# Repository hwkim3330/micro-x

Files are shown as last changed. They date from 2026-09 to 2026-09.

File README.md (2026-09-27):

# MICRO X — Rev C

*An independently designed 14-servo small biped robot (Microduck-compatible 61-obs → 14-action, 50 Hz policy interface) with original CAD, printability/interference/balance checks and a MuJoCo model, all numbers generated from measured artifacts. Rev C is digitally verified only; no physical build or walking test yet. [Browser 3D viewer](https://hwkim3330.github.io/micro-x/web/).*

**소유자 hwkim3330이 제작·판매를 목표로 개발하는 상업용 독자 설계 소형 두발 로봇.** 공룡을 고집하지 않습니다. 넓은 부리와 큰 눈, 크림 몸에 호박색 부리·발, 두꺼운 벽. Microduck의 14축 정책 인터페이스(61 관측 → 14 행동, 50 Hz)를 그대로 쓰되, 기구·외장·서보 배치·전장 자리는 독자 설계입니다. 원본 기구를 그대로 쓰는 비상업 비교 시험기 [Micro Rex](https://github.com/hwkim3330/micro-rex)는 별도 저장소로 보존합니다.

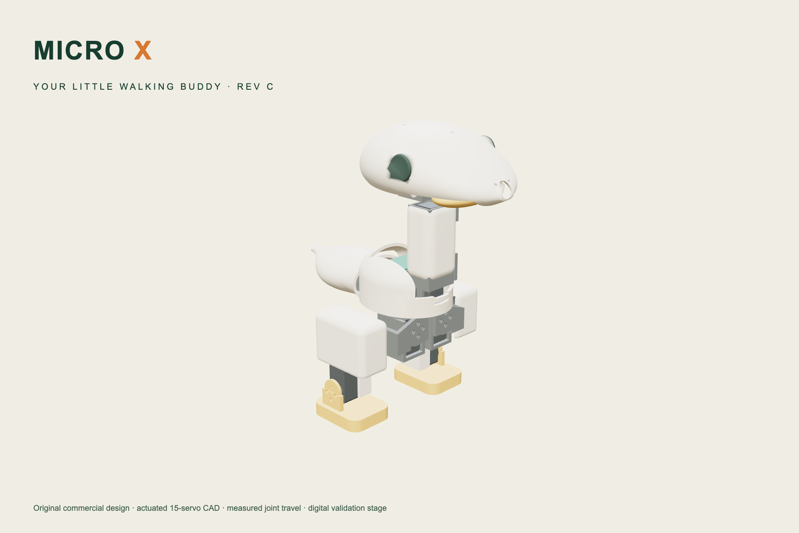
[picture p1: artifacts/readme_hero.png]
Micro X Rev C — 실제 CAD 렌더


[제품 페이지 · 3D 뷰어](https://hwkim3330.github.io/micro-x/web/) · [학습 Lab](https://hwkim3330.github.io/micro-x/web/lab.html) · [보행 실험](https://hwkim3330.github.io/micro-x/web/simulator.html) · [설계](docs/DESIGN.md) · [조립](docs/ASSEMBLY.md) · [목표와 진행 기준](PROJECT_GOAL.md)

**현재 단계: Rev C 구동 설계 · 디지털 검증 완료, 실물 검증 전.** 출력·조립·보행·내구 시험은 아직 없습니다. 판매 가능한 완제품이 아닙니다.

## Rev C까지 바뀐 것

| | Rev A | Rev B → C |
|---|---|---|
| 설계 자세 | HOME(다리 굽은 자세) 측정 → 축이 5° 기울고 브래킷이 사선 | **qpos 0(곧게 선 자세) 측정 → 모든 축이 정렬, 브래킷이 평평하게 출력** |
| 서보 고정 | 관절마다 판 두 장으로 감싸는 클레비스 | **기준 로봇과 같은 방식: 한쪽 링크의 U자 채널 + 혼 판 한 장** |
| 출력물 질량 | 422 g | Rev B 347 g → **Rev C 440 g** (벽 2.4 → 3.0 mm, 20개 부품; 튼튼함을 위해 되돌린 부분) |
| 가동 범위 | 추측한 값을 모델에 기입 | **`tools/travel.py`가 0.05 rad씩 돌려 측정**, 그 값이 곧 MuJoCo 관절 한계 |
| 머리 | 타원체 한 덩이 | 단면 8개 로프트의 둥근 머리, **넓은 호박색 부리**, 렌즈 후드 코, **쉘과 한 몸인 Ø22 버튼 눈**(부품 아님) |
| 출력성 | 미측정 | **`artifacts/printability.json`**: 20개 전부 220×220 침대, 최대 오버행 27 % |

## 숫자

아래 표는 전부 `artifacts/`의 JSON에서 `tools/report.py`가 채웁니다. 손으로 적은 성능 숫자는 없습니다.

<!-- measured:summary -->
| 항목 | 값 | 출처 |
|---|---|---|
| 출력 부품 | 20개, 436.2 g (PLA 꽉 찬 기준, 실제 인필은 더 가벼움) | `artifacts/parts.json` |
| 구매품 | 18개, 399.0 g (카탈로그) | 같은 파일 |
| 모델 총질량 · 무게중심 | 834.3 g, 무게중심 z 141.68 mm, 지지영역 여유 12.71 mm | `artifacts/balance.json` |
| 간섭 | 설계 자세 정적 겹침 0건 / 측정 가동 범위 안 스윕 충돌 0 | `artifacts/interference.json` |
| 출력성 | 20개 모두 220×220 침대, 최악 오버행 30 %, 침대 접촉 0 mm² 4개(skull, right_upper_leg, left_upper_leg, neck_sleeve)는 브림/서포트 필요 | `artifacts/printability.json` |
| 공식 가중치 (무수정) | 15회 중 15회 직립, 추종 게이트 6/15 통과 | `artifacts/compat_evaluation.json` |
<!-- /measured -->

## 측정된 가동 범위

`tools/travel.py`가 관절마다 0.05 rad씩 돌려 정확한 STEP 불리언으로 충돌을 찾은 값이고, 그대로 MuJoCo 관절 한계가 됩니다.

<!-- measured:travel -->
| 관절 | 왼쪽 | 오른쪽 |
|---|---|---|
| 고관절 요 | -28.6° … +29.8° | -29.8° … +28.6° |
| 고관절 롤 | -22.9° … +20.1° | -20.1° … +22.9° |
| 고관절 피치 | -90.0° … +51.6° | -51.6° … +90.0° |
| 무릎 | -90.0° … +63.0° | -63.0° … +90.0° |
| 발목 | -31.5° … +31.5° | -31.5° … +31.5° |
| 목 피치 | -11.5° … +37.2° | (단일) |
| 머리 피치 | -34.4° … +34.4° | (단일) |
| 머리 요 | -114.6° … +43.0° | (단일) |
| 머리 롤 | -5.7° … +8.6° | (단일) |
| 턱 | +0.0° … +5.7° | (단일) |

탐색 상한: 고관절 요 ±30°, 고관절 롤 ±23°, 고관절 피치 ±90°, 무릎 ±90°, 발목 ±90°, 목 피치 ±60°, 머리 피치 ±90°, 머리 요 ±115°, 머리 롤 ±25°, 턱 ±40°. 상한에 도달한 값은 기구가 아니라 탐색 범위가 끝난 것입니다.
<!-- /measured -->

## 정적 기울기 한계

<!-- measured:tip -->
| | Micro X | **Microduck (원본)** | **Micro Cat** |
|---|---|---|---|
| **뒤로 기울기** | 5.5° | 8.5° | 17.7° |
| 앞으로 기울기 | 18.0° | 13.25° | 19.25° |
| 옆으로 기울기 | 24.9° | 23.8° | 25.25° |
| 무게중심 높이 (mm) | 138.0 | 141.1 | 135.7 |
| 질량 (g) | 834.3 | 737.2 | 872.5 |

`tools/tip_study.py`: 기울기마다 몸을 회전시켜 바닥에 내려놓고 접촉점을 다시 계산합니다. 원본은 HOME에서 **발바닥이 평평하지 않아** 뒤꿈치 선으로 서 있고, 무게중심이 그 선보다 21 mm 앞에 있어 발끝이 닿을 때까지 앞으로 넘어갑니다. 표의 값은 그렇게 안정된 자세부터 넘어질 때까지의 각도입니다. 강체·정적이며 접촉 강성·마찰·동역학은 없습니다.
<!-- /measured -->

## 속도·회전 숫자는 믿지 마세요

<!-- measured:harness -->
| 모델 | 전진 명령 추종 (최대) | 회전 명령 추종 (최대) |
|---|---|---|
| microduck_reference | 45 % | 9 % |
| micro_x | 33 % | 1 % |

기준 로봇 자신이 자기 명령을 못 따르므로, **이 하네스의 절대 속도·회전 숫자는 설계 근거로 쓸 수 없습니다.** 같은 하네스 안에서의 모델 간 상대 비교만 의미가 있습니다.
<!-- /measured -->

## 설계 개요

- **관절**: 좌우 고관절 요·롤·피치, 무릎, 발목(10) + 목 피치, 머리 피치·요·롤(4) + 턱(1).
- **피벗·축**: `engineering/functional_layout.json` (기준 로봇을 qpos 0에서 측정한 기능 치수). 서보 몸체 방향만 두 곳에서 바꿨고 이유를 같은 파일에 적었습니다.
- **서보**: XL330급. 인터페이스 치수와 발주 전 확인 항목은 `engineering/actuator_interface.json`. 케이스 홀 패턴은 아직 모델에 없습니다.
- **패키징**: 2S 18650급 배터리는 꼬리 커버 안, 보드(최대 50 × 27 mm)는 고관절 서보 위 데크, 카메라는 주둥이 끝.
- **외장 7개**(몸통·목 커버·머리·아래 부리·꼬리·발 2)만 보이고 나머지는 프레임. 눈은 쉘과 한 몸인 버튼, 손·발톱 없음.
- **배색**: 따뜻한 크림 쉘 + 호박색 부리·발 + 그래파이트 관절. 몸통 아래는 도색으로 한 톤 낮춥니다.
- **튼튼함**: 쉘 벽 3.0 mm, 서보 채널 벽 3.0 mm, 고관절 리브 4 mm + 상하 거싯, 발바닥 4 mm 스킨. 낙하 시험은 아직 없습니다.

## 재생성

```sh
uv venv --python 3.11 .venv && uv pip install --python .venv/bin/python -r requirements.txt
.venv/bin/python cad/build.py            # 20 STEP/STL + GLB 리그 + parts.json
.venv/bin/python cad/compat_model.py     # models/micro_x_14.xml, models/rig.json
.venv/bin/python tools/travel.py         # 관절별 가동 범위 측정 → engineering/joint_travel.json
.venv/bin/python cad/compat_model.py     # 측정값을 관절 한계로 반영
.venv/bin/python tools/interference.py   # 정적 + 가동 범위 안 간섭
.venv/bin/python tools/balance.py && .venv/bin/python tools/printability.py && .venv/bin/python tools/documents.py
.venv/bin/python tools/validate.py && .venv/bin/python -m unittest discover -s tests

uv venv --python 3.12 .venv-policy && uv pip install --python .venv-policy/bin/python -r requirements-policy.txt
.venv-policy/bin/python tools/fetch_compat.py
.venv-policy/bin/python tools/evaluate_compat.py --seconds 10 --seeds 3
.venv-policy/bin/python runtime/training_service.py   # Lab http://127.0.0.1:5201/web/lab.html

npm ci && node --test tests/learning.test.mjs
CHROME_PATH=/path/to/chrome node tools/test-web.mjs && node tools/test-lab.mjs && node tools/test-simulator.mjs && node tools/test-compat-web.mjs
```

## 권리와 판매 방향

원본 기구·CAD 생성 소스·모델·도면은 소유자 권리를 유보합니다(소유자의 상업 이용을 제한하는 비상업 라이선스가 아닙니다). 웹·도구 코드는 MIT, Three.js는 MIT. 공식 추론 코드·가중치(Apache-2.0)는 저장소에 재배포하지 않고 로컬 캐시에만 내려받습니다. 상세: [LICENSE](LICENSE) · [THIRD_PARTY.md](THIRD_PARTY.md) · [PROVENANCE.md](docs/PROVENANCE.md). 제품명·디자인 권리 검토와 공급자 견적은 출시 전 별도 게이트입니다.

### 실제 실행 보드

소형 Radxa Zero 3W 4GB를 첫 실물 검증 후보로 정했습니다. 보행·행동 계산은 로봇 내부, 학습은 PC에서 실행하는 구조입니다. [배선 구상·전체 신경망 CPU 실측·미검증 항목](docs/ONBOARD_COMPUTE.md)을 확인하세요. 실제 보드·전원 검증 전이며 기존 7.4 V BAM 실험은 XL330의 실물 전원 사양이 아닙니다.

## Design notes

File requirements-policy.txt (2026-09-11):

mujoco==3.10.0
numpy>=2,<3
onnxruntime==1.24.1
onnx>=1.17,<2
torch==2.10.0
better-actuator-models @ git+https://github.com/Rhoban/bam.git@62bd8ce12154340be97e06f7f41a0ca8f116d967

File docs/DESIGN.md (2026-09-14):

# Micro X Rev C — 설계

Rev C는 Rev B 위에서 **공룡 형상을 버리고, 넓은 부리와 큰 눈을 가진 둥근 머리로 바꾸고, 벽을 두껍게** 한 판입니다. 기구·측정·검증 방식은 Rev B 그대로입니다. 아래 Rev B 설명이 그대로 적용되며, Rev C 차이는 이 절 끝에 있습니다.

Rev B는 Rev A를 버리고 **기준 로봇의 관절 배치를 측정해 그 위에 처음부터 다시 그린 설계**입니다. 바뀐 것은 세 가지입니다.

1. **설계 자세를 바꿨습니다.** 예전에는 HOME 자세(다리가 굽은 자세)에서 치수를 쟀기 때문에 모든 피벗 축이 5° 기울어 있었고, 브래킷마다 기울어진 형상이 필요했습니다. Rev B는 `qpos = 0`(다리가 곧게 선 자세)에서 측정합니다. 그래서 **모든 관절 축이 X·Y·Z에 정렬**되고, 브래킷이 전부 단순한 직육면체 조합이 되어 서포트 없이 평평하게 출력됩니다. 정책의 HOME 각도는 기구에 굳히지 않고 그냥 관절 각도로 둡니다.
2. **서보 고정 방식을 기준 로봇과 같게 했습니다.** Rev A는 관절마다 판 두 장으로 서보를 감싸는 클레비스 구조여서 부피가 크고 서보가 밖으로 드러났습니다. Rev B는 **서보 몸체가 한쪽 링크의 U자 채널에 들어가고, 이웃 링크는 혼에 볼트로 붙는 판 한 장**입니다. 부품이 얇아지고 가벼워졌습니다(출력물 422 g → 347 g).
3. **가동 범위를 추측하지 않고 측정합니다.** `tools/travel.py`가 관절마다 0.05 rad씩 돌려 가며 정확한 STEP 불리언으로 충돌을 찾아 **실제로 움직일 수 있는 각도**를 구하고, 그 값이 그대로 MuJoCo 관절 한계가 됩니다.

좌표계는 mm, X 앞, Y 왼쪽, Z 위, 바닥 Z=0, 몸통 기준 프레임 Z=120입니다. 생성기는 `cad/build.py`, 배치는 `cad/layout.py`, 서보 인터페이스는 `cad/servo.py`, 측정값은 `engineering/functional_layout.json`입니다.

## 구성

| 부위 | 내용 |
|---|---|
| 몸통 | 섀시(바닥판·고관절 요 서보 박스 2개·전장 데크·배터리 트레이) + 알 모양 쉘(아래는 직선 통, 위는 돔) |
| 꼬리 | 배터리 커버. 2S 18650급 팩(65 × 37 × 19)이 들어가고 M3 2개로 트레이에 고정 |
| 다리 | 요·롤 브래킷 → 고관절 브래킷 → 허벅지 쉘(고관절 피치 + 무릎 서보) → 종아리(발목 서보) → 발 |
| 목 | 두 서보가 세로로 쌓인 튜브 + 둥근 커버. 커버는 목과 함께 기울어짐 |
| 머리 | 요크(머리 요 서보) → 머리 프레임(머리 롤 + 턱 서보, 카메라 벽, 두개골 보스) → 두개골 로프트 + 아래턱 |

머리는 **단면 8개를 잇는 로프트**입니다. 눈 위가 가장 넓고 앞으로 길게 좁아지며, 넓은 호박색 아래 부리가 입을 덮습니다. 기준 로봇의 머리 외형(122 × 92 × 59 mm)에 맞춰 134 × 108 × 60 mm로 잡았습니다. 눈·손·발톱 같은 **떨어질 부품은 없습니다.** 눈은 쉘에서 8 mm 뿌리로 솟은 Ø22 버튼(테두리가 수직이라 도색 경계가 선명), 카메라는 코 자리 렌즈 후드 안에 있습니다.

## 서보 15개의 자리

| 관절 | 서보 몸체가 있는 링크 | 혼 판을 가진 링크 |
|---|---|---|
| 고관절 요 | 몸통 섀시 | 요·롤 브래킷 |
| 고관절 롤 | 요·롤 브래킷 | 고관절 브래킷 |
| 고관절 피치 | 허벅지 | 고관절 브래킷 |
| 무릎 | 허벅지 | 종아리 |
| 발목 | 종아리 | 발 |
| 목 피치 | 목 튜브 | 몸통 섀시 |
| 머리 피치 | 목 튜브 | 머리 베이스 |
| 머리 요 | 요크 | 머리 베이스 |
| 머리 롤 | 머리 프레임 | 요크 |
| 턱 | 머리 프레임 | 아래턱 |

피벗과 축은 기준 로봇 측정값 그대로입니다. 서보 **몸체 방향**만 두 곳에서 바꿨고(`design_servo_overrides`), 이유를 파일에 적었습니다: 머리 롤 서보는 장축을 세워 좁은 뒤통수에 넣었고, 턱 서보는 넓은 쪽으로 향하게 해 부리 팔이 머리 요 서보를 피하도록 했습니다.

## 측정된 가동 범위

`engineering/joint_travel.json`. 왼쪽/오른쪽이 다른 것은 실제로 다르기 때문입니다(브래킷이 좌우 대칭이라 회전 방향에 따라 닿는 곳이 다름).

| 관절 | 측정 가동 범위 | 서보 정격 기준 |
|---|---|---|
| 고관절 요 | -26° … +30° | ±30° |
| 고관절 롤 | -20° … +17° | ±23° |
| 고관절 피치 | -90° … +63° | ±90° |
| 무릎 | -90° … +63° | ±90° |
| 발목 | ±52° | ±90° |
| 목 피치 | -12° … +40° | ±60° |
| 머리 피치 | ±34° | ±90° |
| 머리 요 | ±115° | ±115° |
| 머리 롤 | ±17° | ±25° |
| 턱 | 0° … +17° | 0…40° |

목 피치와 턱이 가장 좁습니다. 목은 서보가 세로로 쌓여 몸통 지붕과 가깝고, 턱은 부리가 카메라 벽에 닿습니다. 다음 개선 대상입니다.

## 출력 (artifacts/printability.json)

20개 부품 모두 220 × 220 침대에 들어갑니다. 최대 오버행 면적 비율은 27 %이고, 부품마다 출력 방향이 `models/print/`에 고정되어 있습니다. 대부분의 브래킷은 면 하나를 침대에 붙이고 벽이 전부 수직이라 서포트가 필요 없습니다. 몸통 쉘은 열린 쪽을 아래로 놓아 테두리 467 mm²가 침대에 닿습니다. 아래턱과 꼬리는 곡면이라 브림이 필요합니다.

## 검증 상태

- 20개 출력 부품 모두 STEP 왕복·닫힌 메시 통과, 347 g(PLA 꽉 찬 기준). 구매품 18개 399 g. 모델 총 746 g (Microduck 780 g).
- 설계 자세 정적 겹침 **0건**, 측정 가동 범위 안의 관절별 샘플 충돌 **0건** (`artifacts/interference.json`).
- HOME 자세 기립 높이 119.3 mm, 무게중심 141 mm, 발 지지영역 안 여유 12.2 mm (`artifacts/balance.json`).
- 변경 없는 공식 보행·서기 가중치를 CAD 기반 14축 모델에서 실행: 15회 모두 10초 직립, 속도·방향 기준은 정지·서기 6회만 통과 (`artifacts/compat_evaluation.json`).

## 남은 일

- 서보 케이스 홀 확인 후 몸체 고정 나사 추가, 케이블 경로.
- IMU·마이크·스피커·전원 보드 배치(데크는 50 × 27 mm까지).
- 목 피치와 턱 가동 범위 확대.
- 출력 공차 시편 → 다리 한 쪽 → 전체 조립 → 보행 시험.

## Rev C 차이 (2026-09-14)

| 항목 | Rev B | Rev C | 이유 |
|---|---|---|---|
| 형상 | 티렉스 주둥이 | 둥근 머리 + 넓은 부리, 크림/호박 배색 | 사용자 요청: 공룡 아니어도 되고 귀엽게; Microduck 쪽이 낫다는 평가를 기준으로 비율을 그쪽에 맞춤 |
| 몸통 쉘 | 아래 121 mm에서 끝남 | 116 mm까지 내려 고관절 서보를 덮음 | 서보가 밖으로 드러나 보이던 문제 |
| 턱 서보 | 피벗 y 18 mm | y 14.5 mm | 머리를 기준 로봇 크기로 줄이자 서보가 쉘 밖으로 나가서 안쪽으로 이동 |
| 쉘 벽 | 2.4 mm | 3.0 mm | 낙하 강도. 출력물 347 → 440 g (버튼 눈·긴 부리 포함) |
| 서보 채널 벽 | 2.4 mm | 3.0 mm | 서보 주변이 가장 먼저 깨지는 곳 |
| 고관절 브래킷 | 3 mm 판 두 장 + 리브 | 롤 리브 4 mm + 상하 코너 거싯 | 브래킷을 상자로 닫는 건 롤 서보와 겹쳐 불가; 리브 보강으로 대체 |
| 허벅지 쉘 | 2.1 mm | 3.0 mm, 라운드 6 | |
| 발 | 스킨 2.5 mm | 스킨 4 mm, 판→바닥 연결 4 mm | |
| 눈 | 도색 마스크(좌표가 형상을 못 따라가 얼룩) | 쉘에서 솟은 Ø20 버튼(라운드 테두리) + 앞면 도색 | 곡면 위 접시는 앞쪽이 뚫려 초승달이 되어 버튼으로 바꿈; 부품 아님 |
| 발목 가동 | ±52° | ±32° | 두꺼운 종아리 채널이 발을 더 일찍 막음. 보행 정책 HOME 발목 ±26°는 안에 있음 |
| 정적 여유 | 12.0 mm | 10.6 mm | 부리가 앞으로 나가 무게중심이 앞쪽으로 이동 |
| 총질량 | 746 g | 838 g | Microduck 780 g보다 7 % 무거움 |

무게 증가는 튼튼함의 대가입니다. 서보 토크 여유가 줄었으므로 실물에서 보행이 힘들면 인필을 낮추거나 쉘만 2.4 mm로 되돌리는 것이 첫 조정입니다.

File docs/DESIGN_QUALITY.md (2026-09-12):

> Rev A(2026-09-13)에서 P0 외형 설계가 폐기되었습니다. 현재 설계 원칙과 검증 상태는 [DESIGN_REVA.md](DESIGN_REVA.md)를 보세요. 아래는 P0 기록입니다.

# Cute appearance and measurable durability

The user requested a cute, robust product that can compete with Microduck. We treat that as a design and verification objective, not an achieved comparative claim.

## Implemented in the current CAD

- Large eyes now have dark pupils and two highlights in the GLB paint mask. These marks are a paint/multicolor finish specification, not extra detachable CAD components. STL remains geometry-only; no paint adhesion or wear resistance is implied.
- Adhesive-only eye spheres are replaced by caps with an integral Ø10 mm rear boss, Ø2.6 mm by 7 mm pilot and a 2 mm integrated skull support plate with Ø3.4 mm clearance. Intended fastening is an M3 plastic thread-forming screw fitted from inside the skull. Candidate M3×8 length with a 1 mm washer gives approximately 5 mm engagement; verify actual chosen screw head, thread, torque and clearance before ordering. Thread-forming fit is material/process specific and has not been validated.
- Forearms, their torso posts and decorative toe projections are removed. Continuous rounded soles retain the existing ankle interface. This reduces parts and exposed projections; strength and drop performance still require physical tests.
- Q4 shares the same new eye/head geometry, avoiding two independent cosmetic/retention designs.

## What must be measured

`engineering/acceptance.json` records proposed test targets with **null results**. Eye retention, loaded joint endurance, drop behavior, drive-module replacement time and actual walking tests remain open. No physical robustness conclusion follows from watertight STL or lack of static CAD overlap.

Cost reduction must preserve load capacity and service life. Current load screening rejects the cheaper B2 candidate under the stated assumptions; see `docs/PLATFORMS.md`. The next drive design needs verified motor data, supported shafts/bearings, cable strain relief and a locking/retention strategy.

Both eye print STLs place the rear boss on the bed; support is still needed under the cap rim. Q4 shared parts reuse the exact B2 print STL bytes, preserving the same print setup rather than silently rotating a common part differently.

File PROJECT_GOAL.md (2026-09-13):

# Micro X product design goal

Owner: hwkim3330. Commercial, independently designed T-rex companion robot that keeps the Microduck 14-axis policy interface. The noncommercial Micro Rex repository stays separate as the unchanged-Microduck reference rig.

## Direction as of 2026-09-13 (Rev B)

User direction, in order: the P0 appearance was rejected; make X as cute as the original Microduck; drop parts that can break off (eyes, hands, claws); this is for sale, so do it properly and make it easy to print. Rev B therefore:

- measures the reference robot's joint layout at qpos 0 (straight legs) instead of the HOME pose, so every axis is world-aligned and every bracket prints flat;
- holds each servo the way the reference does - body in a U-channel on one link, a single horn plate on the next - giving 20 printed parts at 347 g;
- has no eye, hand or claw parts: the nose camera is the eye and the eyes are painted;
- measures each joint's collision-free travel by exact-boolean bisection and uses those numbers as the MuJoCo joint limits, instead of declaring a range and hoping;
- reports printability (bed fit, overhang fraction, bed contact) per part;
- generates the 14-axis MuJoCo model from the CAD meshes and re-runs the unchanged official weights on it;
- ships a Lab where the same evaluation protocol covers the official weights and locally trained checkpoints, and replays recorded gaits on the real CAD rig.

## Acceptance and limits

- No Microduck CAD, STL, body transforms, trained policies or hardware-derived model data in this repository. Functional joint pivots/axes are attributed measurements.
- Every printable part is a valid closed CAD solid and a watertight mesh; the HOME assembly has no exact-STEP overlaps; single-joint sampled sweeps are recorded with any remaining collision samples listed.
- Servo interface dimensions are purchased-part data; case hole pattern, cable exits and voltage rail must be confirmed before ordering.
- Static CAD, simulation upright-ness and ONNX loading are not walking acceptance. Acceptance needs measured velocity/yaw tracking, fall rates and reproducible training, then physical trials.
- Cost model uses retail servo pricing and stated assumptions; it is not a quote.

## Completion ledger

- [x] Rev B actuated CAD: 20 printed parts, 15 servo envelopes, battery/board/camera placements, STEP/STL/GLB, drawings and BOM
- [x] Chibi appearance per user request; README portrait rendered from the actual CAD
- [x] Static interference clear in the design pose; per-joint sweeps clear inside the measured travel; travel and printability published as artefacts
- [x] CAD-derived 14-axis dynamics model with the pinned adapter; unchanged official weights evaluated on it
- [x] Lab: anatomy, 14-axis studio (train / evaluate / compare / download), gait replay on the CAD rig, 1-axis teaching example, voice
- [x] Local simulator drives the CAD rig from MuJoCo qpos with official or trained policies
- [ ] Servo case retention and cable routing after the drawing is confirmed
- [ ] IMU, microphone, speaker, power board placement; compute carrier design
- [ ] Printed coupons, one leg, full assembly; physical fit, endurance, drop, thermal tests
- [ ] Walking acceptance (measured tracking, fall rate) in simulation, then on hardware
- [ ] Supplier quotes, DFM, market/rights review before any sale

## Historical

P0 appearance-only shells and the Q4 quadruped packaging study are archived (`models/q4/`, `models/archive/p0_parts.json`, git history). The primitive 14-axis study model is kept at `models/archive/micro_x_14_primitive_study.xml` so its recorded evaluations stay verifiable.

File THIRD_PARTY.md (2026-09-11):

# Third-party software

- Three.js 0.180.0, MIT, bundled under web/vendor/three/. Upstream license retained as LICENSE. Source: https://github.com/mrdoob/three/tree/r180
- CadQuery 2.8.0 (Apache-2.0), Open CASCADE via cadquery-ocp, trimesh 4.11.1 (MIT), NumPy (BSD), ReportLab (BSD): build-time dependencies, not bundled in the website. Their licenses are not automatically assigned to original generated designs.
- Puppeteer 25.10.0 (Apache-2.0): test-time dependency.

No upstream Microduck mesh, CAD or hardware XML is included. Functional joint measurements are attributed in engineering/functional_interface.json. Pinned Apache-2.0 inference software and policy weights are fetched into the excluded local cache by tools/fetch_compat.py; engineering/policy_sources.json records hashes and license sources. The official mjlab training environment is installed separately under its own licenses. These software licenses do not relicense upstream hardware.

Camera mounting dimensions reference the Raspberry Pi Camera Module 3 Standard manufacturer drawing (linked in docs/FUNCTIONS.md). No manufacturer drawing or CAD is bundled. rpicam-apps and ALSA utilities are external system dependencies, not distributed here. The original synthesized chirp and runtime source are MIT under the root LICENSE scope.

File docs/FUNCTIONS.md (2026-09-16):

# 카메라·음성·감각 기능

기본형은 코 중앙 카메라 1개와 표정용 눈 2개를 사용합니다. Rev A에서는 카메라 벽이 머리 프레임에 통합되어 요·롤 서보와 함께 움직입니다. 두 카메라를 쓰는 스테레오 깊이 인식 버전은 보류 상태입니다. [버전별 설계 조건](../engineering/camera_variants.json)에 동기화, 보정, 깊이 오차, 연산 장치, 머리 질량 및 목 토크 검증을 명시했습니다. 렌즈 보호 테두리·배선 고정·내부 정비 구조는 설계 목표이며 낙하 강도가 검증됐다는 뜻은 아닙니다.

현재는 **카메라 장착 구조 + 로컬 장치 서비스 초안**입니다. 카메라, 마이크, 스피커가 실물 로봇에 모두 장착되어 작동한다는 뜻은 아닙니다. Microduck보다 높은 성능은 제품 목표이며 입증된 결과가 아닙니다.

| 기능 | Micro X 현재 구현 | 다음 검증 |
|---|---|---|
| 카메라 | Camera Module 3 Standard용 독자 브래킷, 코 Ø18 mm 포트, 명시적으로 활성화하는 JPEG 촬영 코드 | 실물 체결·케이블·초점·주변부 가림·지연 |
| 음성 입력 | ALSA 2초 모노 녹음 경로, 별도 활성화 필요 | 마이크 선정·기구 장착·모터 소음·에코 제거 |
| 소리 | 자체 합성한 짧은 울음소리, ALSA 재생 경로 | 스피커·앰프·음향 공간·음량 |
| 대화·비전 | 미구현 | 인식 모델, 연산 장치, 지연과 전력 측정 |
| IMU·거리·발 접촉 | 요구사항 기록, 부품 미선정 | 회로·배선·보정·제어 주기 |
| 보행 | Rev A 15서보 구동 CAD, CAD 기반 동역학 모델, 공식 가중치 시뮬레이션 | 실물 조립·전원·제어·보행 |

## 비교 기준

[Microduck 런타임 소스](https://github.com/pollen-robotics/microduck/tree/bc41fb5c9a9b39894669c1e022e375cf83800382)는 게임패드 보행, 일어나기 등의 동작과 `mediad` WebRTC 영상, 소리 기능, `tofd` 거리 센서 서비스를 제공하거나 문서화합니다. 서비스 존재가 모든 판매 기기의 센서 탑재를 의미하지는 않습니다. Micro X에는 아직 WebRTC 영상, 보행 제어, 통합 음성 대화가 없습니다. 현재 완성도에서는 이 기능들을 따라잡는 작업이 먼저 필요합니다.

차별화 목표는 귀여운 표정과 자체 울음소리, 자동초점 카메라, 수리하기 쉬운 공용 구조, 모터 소음 속에서의 음성 입력입니다. 비교 실험과 원가 견적 없이 성능 우위나 더 낮은 판매 가격을 주장하지 않습니다.

## 카메라 기구

[제조사 기구 도면](https://datasheets.raspberrypi.com/camera/camera-module-3-standard-mechanical-drawing.pdf)의 PCB 및 구멍 치수만 사용해 브래킷을 직접 설계했습니다. 제조사 CAD나 그림은 재배포하지 않습니다. [카메라 사양](https://www.raspberrypi.com/documentation/accessories/camera.html): Standard 모델, 11.9 MP, 자동초점, 수평 66° / 수직 41°.

- PCB 25 × 23.862 × 1.12 mm; 장착 홀 Ø2.2 mm.
- Rev A 로봇 좌표에서 카메라 벽 X45.5~47.5(머리 프레임 일체), 홀 Y±10.5, Z229.75/242.25, 렌즈 Ø12 포트 (50,0,236). 코 앞면 카메라 포트는 두개골 주둥이에 있습니다.
- 카메라 벽은 `head_frame`의 일부이며 네 M2 체결 위치를 가집니다. 나사 머리·너트·PCB 부품 간섭, FPC 경로(목 4축을 지나 몸통 보드까지), 조립 순서는 실물 확인이 필요합니다.
- 광축 Z236, 주둥이 앞면(X≈64)까지 약 16 mm 깊이의 Ø12 포트입니다. 66° 수평 시야에서 비네팅 여부는 실물 확인 대상이며, 필요하면 포트를 원뿔로 넓힙니다.
- FPC 홈을 두었지만 케이블 굽힘과 몸통까지의 배선은 미완성입니다. Pi Zero 계열에는 맞는 15→22핀 카메라 케이블이 필요합니다.

소형 Radxa Zero 3W 4GB를 첫 실물 검증 후보로 변경했습니다. [실행 위치·배선·검증 조건](ONBOARD_COMPUTE.md)을 참고하세요. 실제 보드에서 전체 비전·보행·신경망을 동시에 시험하기 전에는 확정 부품이 아닙니다. 배터리, 보호 회로, 모터 전원, 로직 전원과 발열 설계도 남아 있습니다.

## 로컬 장치 서비스 실행

Raspberry Pi OS에서 카메라를 연결하고 제조사 [rpicam 사용 안내](https://www.raspberrypi.com/documentation/computers/camera_software.html)에 따라 `rpicam-still --list-cameras`를 먼저 확인합니다. 음성 경로는 ALSA의 `aplay`, `arecord`와 운영자가 설정한 기본 장치를 사용합니다. 공개 Pages는 로컬 장치에 자동 연결하지 않습니다.

```sh
# 장치 목록만 조회: 사진 촬영/마이크 녹음/소리 재생 없음
python3 runtime/device_service.py --probe
# 단위 시험: 명령 대역만 사용, 실제 장치 검증 아님
python3 -m unittest discover -s tests -v
```

활성화는 운영자가 장치에서 수행합니다. 다음 명령은 24자 이상 임의 토큰 파일을 만들며 화면에 토큰을 출력하지 않습니다. 세 활성화 옵션은 각각 생략할 수 있습니다.

```sh
python3 -c 'import os,secrets; f=os.open("device.token",os.O_WRONLY|os.O_CREAT|os.O_EXCL,0o600); os.write(f,secrets.token_hex(32).encode()); os.close(f)'
python3 runtime/device_service.py --token-file device.token --enable-camera --enable-audio --enable-microphone
```

서비스는 `127.0.0.1:8765`에만 바인딩합니다. `GET /health`, `GET /camera/status`는 열거 결과입니다. `POST /camera/snapshot`, `/audio/chirp`, `/audio/sample`에는 `Authorization: Bearer <토큰>`이 필요합니다. 녹음은 요청당 2초이며 자동 시작하지 않습니다. 다른 컴퓨터에 공개하는 서버 용도는 아닙니다.

장치 없음/비활성화/명령 실패는 오류를 반환하며 합성 사진이나 녹음으로 대체하지 않습니다. 음원 재생 명령의 성공도 실제 스피커에서 소리가 났다는 검증은 아닙니다. `artifacts/device_probe.json`은 개발 호스트의 열거 기록이며 로봇 탑재 부품 목록이 아닙니다.

## 귀여움과 권리

눈동자와 하이라이트는 도색 표현, 울음소리는 `runtime/sound.py`에서 직접 합성한 예시입니다. 제조사나 다른 로봇의 음원을 추출하지 않았습니다. 소프트웨어와 자체 합성 WAV는 MIT, 원본 CAD는 루트 LICENSE 범위를 따릅니다.

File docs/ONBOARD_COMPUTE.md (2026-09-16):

# X의 실제 실행 보드

소형화와 원본 실행 환경 재현을 우선해 **Radxa Zero 3W 4GB**를 첫 실물 검증 후보로 정합니다. 2GB는 동시 부하 시험 후 원가 절감 후보이며, Pi 5/CM5는 연산 여유가 부족할 때 비교할 대안입니다. 아직 실제 보드에서 측정하지 않았습니다.

[공식 Microduck 설치 문서](https://github.com/pollen-robotics/microduck/blob/6507d2e960417aaa4ecd38eccf59b2dcf586ecd2/docs/robot/install-dev.md)는 Radxa Zero 3와 Armbian을 지정합니다. 원본 재현용 보드로는 이 구성을 유지합니다. [Radxa 사양](https://docs.radxa.com/en/zero/zero3)은 RK3566 Cortex-A55, 65×30 mm입니다. Radxa에서 현재 X의 Pi 카메라 드라이버가 그대로 작동한다고 가정하지 않습니다.

[CM5](https://www.raspberrypi.com/products/compute-module-5/)는 Cortex-A76 기반이며 모듈 크기 55×40×4.7 mm입니다. 이 치수는 캐리어·냉각·커넥터를 제외합니다. 제조사는 최소 2036년 1월까지 생산을 명시합니다. 실제 구매가는 구성·유통·시점에 따라 확인해야 하므로 현재 BOM에 확정 가격을 넣지 않습니다. [Pi 5](https://www.raspberrypi.com/products/raspberry-pi-5/)는 기존 Camera Module 3 경로를 비교할 대안입니다. CM5의 캐리어와 카메라 FFC 연결은 별도 설계해야 합니다.

## 무엇을 어디서 실행하는가

| 기능 | 실행 위치 | 목표 및 상태 |
|---|---|---|
| 보행 ONNX, IMU 자세·관절 입력, 모터 목표 | 로봇의 Linux 보드 | 50 Hz / 20 ms 주기. 실물 I/O 미구현·미검증 |
| 전체 초파리 연결망과 행동 선택 | 같은 보드의 별도 프로세스 | 10 Hz 목표. 지연되어도 보행 프로세스를 막지 않도록 IPC 분리 예정 |
| 중앙 카메라 1개, 영상·표정·음성 I/O | 같은 보드 | 보행과 동시에 부하·발열 검증 필요. 대형 음성 모델은 기본 탑재 가정 없음 |
| 모터 내부 위치·전류 제어 | 각 스마트 서보의 펌웨어 | 신경망 출력을 직접 PWM으로 연결하지 않음 |
| 전원 감시·watchdog | 별도 소형 감독 MCU/회로 후보 | 칩과 펌웨어 미선정. Linux 정지 시 모터를 관리하는 경로 필요 |
| PPO 학습·대량 MuJoCo/Warp 시뮬레이션 | RTX 3090 개발 PC | 현재 실제 실행한 경로. 학습 결과 ONNX만 보드로 이전 |
| 웹 3D 화면 | 휴대폰/PC 브라우저 | 공개 Pages는 정적 화면. 로봇 보드에서 3D 렌더링할 필요 없음 |

```mermaid
flowchart LR
  Camera[중앙 카메라] --> Behavior[보드: 인식·신경망 10 Hz]
  Behavior -->|속도·회전과 유효시간| Walk[보드: 보행 ONNX 50 Hz]
  IMU[IMU·관절 피드백] --> Walk
  Walk --> Bus[USB 또는 UART의 반이중 TTL 인터페이스]
  Bus --> Servo[14축 스마트 서보]
  PC[PC: PPO 학습] -->|검증된 ONNX| Walk
  Supervisor[독립 watchdog·전원 감독] --> Bus
```

초기 배선은 Pi의 USB → 호환 DYNAMIXEL TTL 어댑터 → 서보 버스를 검토합니다. GPIO의 일반 UART 선을 반이중 버스에 바로 연결하는 구성으로 확정하지 않습니다. IMU는 SPI/I²C 후보이며 축 정렬·타임스탬프·샘플 지연을 정책 입력과 맞춰야 합니다. 제품 캐리어에는 이 버스 인터페이스와 전원 감독을 통합할 예정이나 회로도/PCB는 아직 없습니다. 부팅 기본 상태는 모터 비활성으로 설계하고, 오래된 행동 명령은 정지 명령으로 바꾸되 실제 넘어짐 상황의 처리는 로봇 검증 후 정합니다.

## 전압 가정부터 바로잡기

[ROBOTIS XL330-M288-T](https://emanual.robotis.com/docs/en/dxl/x/xl330-m288/)는 **3.7–6.0 V, 권장 5.0 V**입니다. 현재 BAM 비교의 7.4 V는 원본 실행 조건을 재현한 시뮬레이션 설정이며 실물 XL330 전원으로 채택하지 않습니다. 2S 배터리를 이 모터에 직결하는 배선도 만들지 않습니다. 모터용 안정화 전원과 보드용 전원을 분리하고 공통 기준 접지·순간 전류·배선·회생/과도 전압을 실제 부품으로 검증해야 합니다. 정격 5 V에서의 모터 모델과 보행 성능 재검증이 필요합니다. 현재 보고서를 실제 하드웨어 호환성의 합격 근거로 쓰지 않습니다.

## 직접 측정한 것과 남은 합격 조건

`tools/benchmark_brain.mjs`로 전체 139,255 뉴런, 2,698,236 연결을 CPU에서 실행했습니다. i7-10700K 호스트에서 30회 준비 후 300회 측정한 10틱 묶음은 p95 약 17.36 ms, p99 약 20.23 ms, 프로세스 최대 RSS 약 197 MiB였습니다. [원시 결과](../artifacts/brain_host_benchmark.json). 화면·카메라·실물 I/O를 포함하지 않은 호스트 측정이며 Pi 성능으로 환산하지 않습니다.

실제 보드에서 Node.js를 설치하고 별도 보관한 고정 Microfly 소스로 같은 명령을 실행합니다. 스크립트가 소스·그래프 SHA-256을 확인합니다.

```sh
node tools/benchmark_brain.mjs /path/to/microfly-reference board-brain-result.json
```

보드 선정의 다음 조건은 30분 이상 카메라·보행·신경망 동시 실행에서 20 ms 보행 주기 지연 분포, 100 ms 신경망 주기, RSS, CPU 온도·클럭 저하·소비전력·저전압을 기록하는 것입니다. 신경망 부하가 보행 주기를 침범하면 먼저 PC로 행동 계산을 분리하여 시험하고, 기체에는 검증된 보행을 남깁니다. 현재 연결된 실물 보드가 없어 ARM 측정, 실제 모터 동작, 최종 배터리 시간은 아직 검증하지 못했습니다.

## 이번 X 보행 진단

[25회 접촉 민감도 시험](../artifacts/contact_sensitivity.json)은 시드 10, 각 10초, 정지/전진 0.1·0.3 m/s/좌우 회전 0.3 rad/s를 비교했습니다. 기본 모델, 마찰 0.8, 좁은 발, 짧은 발, 발 외 접촉 제거 모두 이동 명령 추종 기준을 통과하지 못했습니다. 발 외 접촉을 없애도 기본 결과가 같았고, 기본 전진 시험에서 침투 접촉은 양발과 바닥만 기록됐습니다. 따라서 이 시험에서는 몸체 충돌이 정체의 원인이라는 근거가 없습니다. 물리 접촉을 제거한 후보는 진단용으로만 남기고 기본 모델을 변경하지 않았습니다. 질량·관성·실제 모터 전압을 반영한 후 재학습/검증해야 합니다.

## 보행 모델 크기와 보드 검사

고정된 공식 보행 ONNX는 **793,705 bytes**입니다. 호스트에서 CPU 한 스레드로 100회 준비 후 2,000회 추론한 p95는 **0.043 ms**, 전체 Python/ONNX 프로세스 최대 RSS는 **약 70 MiB**였습니다. [측정 결과](../artifacts/policy_host_benchmark.json). 앞의 신경망 약 197 MiB와 별도 프로세스·별도 시험이며 OS, 카메라 버퍼, 동시 부하를 포함하지 않습니다. 따라서 4GB 선정은 측정 완료된 최소 요구량이 아니라 개발 여유를 둔 후보입니다.

보드에서는 MuJoCo·PyTorch 없이 별도 가상환경의 NumPy와 ONNX Runtime CPU만으로 검사할 수 있습니다. 다음 설치는 ARM 보드에서 아직 실행하지 않았으며 wheel/OS 호환성 확인이 필요합니다. 위 고정 모델을 준비한 후 실행합니다. 모델 파일의 SHA-256이 다르면 검사가 거절됩니다.

```sh
python3 -m venv .venv-board
.venv-board/bin/pip install numpy onnxruntime==1.24.1
.venv-board/bin/python tools/benchmark_policy.py --model /path/to/alpha_walking.onnx --output board-policy-result.json
node tools/benchmark_brain.mjs /path/to/microfly-reference board-brain-result.json
```

이 검사는 모델 추론만 측정합니다. 모터를 연결하거나 구동하지 않으며 센서 입력은 합성 값입니다. 보행 모델의 작은 메모리 요구와 X 몸체에서 잘 걷는지는 별도 문제입니다. 실제 보드의 카메라·IMU·버스 통합과 30분 동시 부하 검사가 끝나야 최종 부품과 RAM 용량을 확정합니다.

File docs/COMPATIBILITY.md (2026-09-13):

# 14축 정책 호환 검증 (Rev A)

목표는 **독자 설계 상업용 Micro X가 Microduck의 정책 인터페이스(61 관측 → 14 행동, 50 Hz)를 그대로 쓰는 것**입니다. 원본 CAD로 돌아가거나 비상업 하드웨어를 재라이선스하는 것이 아닙니다.

## 세 층

1. **Rev B CAD** (`cad/build.py`): 20개 출력 부품 + 15개 서보·배터리·보드·카메라 외형. 관절 피벗·축은 `engineering/functional_layout.json`(기준 로봇을 qpos 0에서 측정한 기능 치수)을 따르고 나머지는 새로 설계.
2. **CAD 기반 동역학 모델** (`cad/compat_model.py` → `models/micro_x_14.xml`): 부품 메시에서 링크별 질량·질량중심·관성을 계산(PLA 꽉 찬 밀도 + 구매품 카탈로그 질량). 관절 한계는 추측이 아니라 `tools/travel.py`가 측정한 실제 가동 범위입니다. 몸통 프레임은 기준 로봇과 같은 120 mm 높이이고, HOME 기립 높이는 119.3 mm입니다. 이전의 원시 도형 연구 모델은 `models/archive/micro_x_14_primitive_study.xml`로 보존.
3. **고정된 공식 추론 코드 + 가중치** (`runtime/compat_env.py`, `.cache/compat/`): 변경 없는 `alpha_walking.onnx`/`alpha_stand.onnx`와 BAM M6 XL330 모터 모델(kp 200, 7.4 V 재현 조건).

## 제어 계약

`engineering/control_interface.json`: 14 액추에이터 이름·순서, HOME 오프셋, 61 관측(자이로 3, 투영 중력 3, HOME 상대 관절 위치 14, 관절 속도 14, 이전 행동 14, 명령 13), 50 Hz 제어 / 200 Hz 물리. 목표 = HOME + 행동, 스케일 1. 턱은 15번째 수동 관절(정책 외)로 모델에 포함되며 `models/rig.json`이 qpos 배열 순서를 기록합니다.

Rev B의 관절 한계는 `engineering/joint_travel.json`의 측정값입니다: 고관절 요 -26°…+30°, 롤 -20°…+17°, 피치 -90°…+63°, 무릎 -90°…+63°, 발목 ±52°, 목 피치 -12°…+40°, 머리 피치 ±34°, 요 ±115°, 롤 ±17°, 턱 0°…+17° (좌우 비대칭). 정책이 그 이상을 명령하면 시뮬레이션에서 관절 한계에 걸립니다.

## 시험 프로토콜

`tools/evaluate_compat.py`: 정지, 전진 0.1 / 0.3 m/s, 회전 0.3 rad/s 명령 × 시드, 각 N초. 넘어짐 = 몸통 기울기 45° 초과 또는 높이 65 mm 미만. 1초 워밍업 후 몸체 좌표 속도 MAE. 통과 = 넘어짐 없음, 전진 MAE ≤ max(0.03, 명령의 25 %), 좌우 ≤ 0.03, 요 ≤ 0.10. 학습 체크포인트는 `--walking-policy`로 같은 프로토콜에 넣습니다(Lab의 "평가 실행").

## 현재 결과

- `artifacts/compat_evaluation.json`: CAD 기반 모델에 변경 없는 공식 가중치. 결과 요약은 Lab 14축 학습 탭의 첫 카드와 `README.md`에 있으며, 모델 SHA256이 파일에 묶여 있어 모델을 바꾸면 테스트가 실패합니다.
- `artifacts/compat_training.json`: 같은 액터를 CPU PPO로 짧게 이어 학습·ONNX 재내보내기 (파이프라인 검증).
- 이전 원시 연구 모델의 기록(`compat_heldout_evaluation.json`, `training_500.json`, `trained_500_evaluation.json`, `official_recipe_x_validation.json`)은 아카이브 모델 SHA256에 묶여 보존됩니다.

원본 Microduck 모델에 같은 프로토콜을 돌린 비교값은 [micro-rex](https://github.com/hwkim3330/micro-rex)의 `tools/evaluate_policy.py`가 만듭니다. 두 결과를 나란히 읽어야 "가중치 호환"의 의미가 정해집니다: 원본에서도 이 하네스의 전진 명령 추종은 미달이므로, X의 미달을 X 기구만의 문제로 보지 않습니다.

## 재현

```sh
uv venv --python 3.12 .venv-policy && uv pip install --python .venv-policy/bin/python -r requirements-policy.txt
.venv-policy/bin/python tools/fetch_compat.py
.venv/bin/python cad/build.py && .venv/bin/python cad/compat_model.py
.venv-policy/bin/python tools/evaluate_compat.py --seconds 10 --seeds 3
.venv-policy/bin/python tools/train_compat.py --updates 10 --steps 256
.venv-policy/bin/python runtime/training_service.py   # Lab에서 학습·평가·재생
```

실물 호환(전압 5 V 재보정, 실제 관성, 케이블, 접촉)과 생산 준비는 별도 미해결 과제입니다.

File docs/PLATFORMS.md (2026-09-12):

> 기록 문서. B2/Q4 13/15축 계획은 Rev A의 14+1축 구동 설계로 대체되었습니다. [DESIGN_REVA.md](DESIGN_REVA.md) 참고.

# Micro X B2 and Q4 product platforms

User confirmed that the primary product must walk on two legs and requested an additional four-legged model. Locomotion is required, not an optional animation. P0 geometry is a packaging study, not that finished locomotion mechanism.

| Item | B2 primary biped | Q4 additional quadruped |
|---|---|---|
| Candidate leg axes | 5 per leg: hip roll/pitch, knee pitch, ankle pitch/roll | 3 per leg: hip roll/pitch, knee pitch |
| Common head axes | yaw, pitch, jaw | yaw, pitch, jaw |
| Candidate total | 13 actuators | 15 actuators |
| Target mass, assumption | 1.5 kg | 1.8 kg |
| Loaded support legs for initial screen | 1 | 2 |
| First locomotion requirement | Controlled straight-line steps, then turning | Crawl with three-foot support, then dynamic gait if verified |

B2 initially omits hip yaw; turning capability must be demonstrated, not inferred from axis count. Q4's torque screen uses two support legs as a demanding load-sharing case, not proof that a trot is viable. The tail and small cosmetic arms remain passive in the axis budget.

## Shared design and assembly files

`models/q4/micro_x_q4.step` and `.glb` are the new four-legged assembly. It contains 20 part instances using 14 existing original designs plus two new side rails. The front/rear leg-and-foot designs are repeated, rather than independently remodeled. Across B2 and Q4 there are 18 unique printable designs at this stage; this does not imply a measured cost saving.

Q4 leg instances use X offsets +64 mm (front) and -46 mm (rear) from the common leg geometry, and Y offsets +6 mm left / -6 mm right. Hip axes therefore have X = +50 / -60 mm and Z = 143 mm. Rail centers are Y = ±47.2 mm; thickness 5.4 mm. Rails have M3 clearance axes at X = -60 / -14 / +50, Z143. A 0.5 mm nominal gap separates rail and existing torso boss, and a 0.1 mm gap separates rail and leg. These are nominal CAD dimensions, not confirmed printer fits.

The two rails are packaging supports. Anti-rotation, fastener retention, bearing spacing, flexural strength and motor reaction paths are not complete. The common solid leg must be replaced with actual articulated links and motor cartridges before either model walks.

## Load and cost screening

Run `python3 tools/platform_screen.py` to generate `artifacts/platform_screen.json`. The simple calculation is `mass × gravity / supporting legs × horizontal moment arm × load multiplier`.

Under the stated assumptions, B2 requires 1.103 N·m and Q4 0.794 N·m. A hypothetical 30% of the candidate's 30 kg·cm stall value is 0.883 N·m: B2 **fails this assumed screen**, and Q4 has only 1.11× margin. The 30% factor is an assumption, not measured continuous performance. Neither result approves the motor. Link self-weight, acceleration, impacts, thermal conditions and real geometry must be included in the next model.

The family-price comparison for 13 or 15 axes is not a final BOM. The head may use smaller servos and the legs may require stronger ones. Sharing a module is worthwhile only if the same load, speed and supply requirements are met.

## Next engineering gates

1. Freeze load cases, physical link lengths, speed, payload and service life targets. Keep assumptions editable until measured.
2. Obtain dimensioned manufacturer drawings and continuous-duty evidence, or measure samples. Choose bearings and shaft supports before committing outer-shell tooling.
3. Design a pitch/knee cartridge and separate B2 ankle unit. Check actual motor, horn, screws, connectors and cable sweeps in the assembly.
4. Build calibrated articulated simulation and controllers; report falls, motor saturation and thermal limitations rather than just rendering motion.
5. Bench-test a loaded single leg, then a restrained platform, then untethered locomotion. Record physical evidence before calling it a walking product.
6. Freeze EVT/DVT/PVT and supplier DFM gates before production procurement. Market compliance and intended user age remain to be determined.

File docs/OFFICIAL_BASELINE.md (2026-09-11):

# Official baseline before Micro X transfer

The official simulator and training source are installed separately from this
commercial design repository. Original hardware assets are not shipped as X.

## Executed official browser trial

Source: <https://huggingface.co/spaces/pollen-robotics/microduck-simulator>,
revision `023172c8a7d629b5258d90364c13bafe013abbfa`.
Local Vite server, Chrome and SwiftShader ran real MuJoCo WASM physics and ONNX.
Keyboard forward input advanced 10.04 simulation seconds and displaced the
robot 1.0291 m forward. Actor observations had 61 entries and no page errors
were recorded. This was a single trial, without continuous fall monitoring.
Approximately 4 FPS / 4 Hz appeared in the HUD: real-time performance is not
accepted on this headless rendering setup. This is not a prerecorded replay.
See [raw measurements](../artifacts/official_browser_validation.json).

## Executed official training trial

The unmodified `microduck_rl` revision
`2b25a48b08f1f17bc38c90bb03144c81fbd9ed07` was installed with `uv sync --frozen`
and its lockfile. On the local RTX 3090:

```sh
uv run train Mjlab-Velocity-Flat-MicroDuck --env.scene.num-envs 64 --agent.max-iterations 5 --agent.logger tensorboard
```

All five iterations completed. Checkpoints and normalized ONNX export were
generated; ONNX accepted `[1,61]` and returned finite `[1,14]` values. Actor
weights changed between saved checkpoints. This verifies the training pipeline,
not learned gait quality. The pretrained browser policy and this newly trained
five-iteration policy are different. TensorBoard logs stayed local.
See [version and artifact hashes](../artifacts/official_training_validation.json).

## Applying the recipe to X

`tools/train_official_recipe.py` loads the official registered walking recipe
in that separate virtual environment, replacing the robot spec with X's
primitive dynamics study. It preserves reward definitions, observation/noise
settings, curricula, BAM and PPO. Adaptations are explicit: X collision masks,
foot contact/site names, an angular-momentum sensor, and head COM body selectors
(including the right hip-yaw body retained by the upstream recipe).

```sh
/path/to/microduck_rl/.venv/bin/python tools/train_official_recipe.py --iterations 5 --num-envs 64
```

The first X run exposed a missing `root_angmom` sensor required by the official
reward. The adapter now supplies that actual MuJoCo sensor; the reward was not
removed to bypass the error. X trials are integration checks, not full training
parity, unchanged-weight tracking acceptance or physical compatibility. The
P0 printable shell is still separate from this actuated dynamics study.

The corrected X run completed all five iterations in 64 environments, changed
actor weights and exported a finite `[1,61]` → `[1,14]` ONNX policy.
[X model, adapter and output hashes](../artifacts/official_recipe_x_validation.json)
bind this result to the executed model. The browser workbench's compact CPU PPO
remains a separate harness; the official GPU recipe currently runs via the CLI.

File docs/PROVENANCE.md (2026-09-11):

# Provenance and commercial boundaries

This is a newly initialized repository, not a fork of Microduck or the earlier Micro Rex retrofit. `cad/build.py` constructs geometry from explicit dimensions using CadQuery primitives and lofts; it reads no external robot geometry. Body outlines, joint display pivots and part splits originate in this file. The developer previously inspected Microduck sources, so this is not represented as a formal clean-room legal process.

The old Micro Rex geometry stays in its separate repository. Its pinned upstream Microduck RL README states hardware designs are CC BY-SA-NC, without a version in that notice:
https://raw.githubusercontent.com/pollen-robotics/microduck_rl/2b25a48b08f1f17bc38c90bb03144c81fbd9ed07/README.md

No conversion of those rights to a commercial license is attempted. The general NC restriction is described by Creative Commons at https://creativecommons.org/licenses/by-nc-sa/4.0/ ; that page does not determine the unspecified version of the upstream notice.

Original design data including parametric CAD source is reserved for the owner under the root LICENSE. Software utilities and web application logic are MIT. Three.js is MIT and retains its upstream text. Public GitHub access is not an additional manufacturing grant. This is a chosen publication policy, not a legal opinion establishing ownership or freedom to operate. Micro X is a working name; trademark/design/patent searches and supplier rights review remain product launch gates.

## Supplier research, accessed 2026-09-08

- ROBOTIS XL330-M288 official manual: https://emanual.robotis.com/docs/en/dxl/x/xl330-m288/ . Used for candidate comparison only. No CAD copied.
- Waveshare ST3215 family product page: https://www.waveshare.com/product/modules/st3215-servo.htm . Listed family price $16.99–21.99, different voltage variants; not a negotiated quote or a validated actuator selection. Do not assume the same voltage/torque for every variant.
- FEETECH SCS0009 manufacturer PDF links were located but retrieval failed. No dimensional or torque claims from those unread files were used in this CAD.
- Pollen Robotics Robot HAT repository is Apache-2.0, unlike the noncommercial mechanical model: https://github.com/pollen-robotics/elec_RPI_Robot_HAT . Not bundled or integrated here.

None of the supplier names imply partnership, endorsement or manufacturing approval.

## Functional interoperability measurements

The separate 14-axis study uses joint pivots at HOME (rounded to 0.1 mm) and axes measured from the reference model. `engineering/functional_interface.json` records attribution and the source hash. These measurements are not claimed as exclusive original X artwork. X study surfaces, primitive links, masses and inertias are authored separately; no original hardware meshes or XML are redistributed as X. This is not a legal clearance opinion or relicensing of upstream hardware. The earlier P0-only provenance descriptions do not describe this separate dynamics study.

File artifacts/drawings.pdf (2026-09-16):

# MICRO X Rev C — printed part reference drawings

Actuated chibi T-rex; 14 policy joints + jaw. Millimetres. Design pose (straight legs). Assembly frame: X forward, Y left, Z up, floor Z=0, trunk frame Z=120. 20 printed parts (436.2 g solid PLA equivalent) + 18 purchased items (399.0 g catalogue).
Overall views generated from the actual meshes; use STEP for exact geometry. Not production GD&T; prototype fit and fastener checks are still required.

## Printed parts

left_yaw2roll | link left_yaw2roll | 32.4 x 26.8 x 40.4 mm 17.0 g
left_hip | link left_hip | 33.5 x 38.1 x 29.3 mm | 6.3 g
left_upper_leg | link left_upper_leg | 62.2 x 31.8 x 44.5 mm 23.1 g
left_lower_leg | link left_lower_leg | 26.8 x 14.4 x 62.5 mm | 8.6 g
left_foot | link left_foot | 58.0 x 46.0 x 38.0 mm 24.9 g
right_yaw2roll | link right_yaw2roll | 32.4 x 26.8 x 40.4 mm 17.0 g
right_hip | link right_hip | 33.5 x 38.1 x 29.3 mm | 6.3 g
right_upper_leg | link right_upper_leg 62.2 x 31.8 x 44.5 mm 23.1 g
right_lower_leg | link right_lower_leg 26.8 x 14.4 x 62.5 mm | 8.6 g
right_foot | link right_foot | 58.0 x 46.0 x 38.0 mm 24.9 g
chassis | link trunk | 131.0 x 62.0 x 51.9 mm 44.5 g
torso_shell | link trunk | 86.0 x 77.2 x 47.8 mm 29.1 g
tail_cover | link trunk | 92.0 x 64.0 x 42.0 mm 39.1 g
neck_link | link neck | 24.8 x 31.4 x 71.7 mm 16.0 g
neck_sleeve | link neck | 31.0 x 34.5 x 61.1 mm 13.4 g
head_base | link head_base | 26.0 x 35.0 x 25.1 mm | 4.4 g
head_yoke | link head_yoke | 31.3 x 37.8 x 32.4 mm 15.4 g
head_frame | link head | 94.2 x 61.9 x 41.7 mm 25.6 g
skull | link head | 134.0 x 110.2 x 54.8 mm 78.0 g
jaw_beak | link jaw | 62.0 x 66.0 x 34.0 mm 11.1 g

## Purchased items (envelopes)

servo_left_hip_yaw | actuator link trunk | 18.0 g XL330-class smart servo envelope; confirm the case hole pattern before
servo_left_hip_roll | actuator link left_yaw2roll | 18.0 g XL330-class smart servo envelope; confirm the case hole pattern before
servo_left_hip_pitch actuator link left_upper_leg 18.0 g XL330-class smart servo envelope; confirm the case hole pattern before
servo_left_knee | actuator link left_upper_leg 18.0 g XL330-class smart servo envelope; confirm the case hole pattern before
servo_left_ankle | actuator link left_lower_leg 18.0 g XL330-class smart servo envelope; confirm the case hole pattern before
servo_right_hip_yaw | actuator link trunk | 18.0 g XL330-class smart servo envelope; confirm the case hole pattern before
servo_right_hip_roll actuator link right_yaw2roll 18.0 g XL330-class smart servo envelope; confirm the case hole pattern before servo_right_hip_pitch actuator link right_upper_leg 18.0 g XL330-class smart servo envelope; confirm the case hole pattern before
servo_right_knee | actuator link right_upper_leg 18.0 g XL330-class smart servo envelope; confirm the case hole pattern before
servo_right_ankle | actuator link right_lower_leg 18.0 g XL330-class smart servo envelope; confirm the case hole pattern before
servo_neck_pitch | actuator link neck | 18.0 g XL330-class smart servo envelope; confirm the case hole pattern before
servo_head_pitch | actuator link neck | 18.0 g XL330-class smart servo envelope; confirm the case hole pattern before
servo_head_yaw | actuator link head_yoke | 18.0 g XL330-class smart servo envelope; confirm the case hole pattern before
servo_head_roll | actuator link head | 18.0 g XL330-class smart servo envelope; confirm the case hole pattern before
servo_jaw | actuator link head | 18.0 g XL330-class smart servo envelope; confirm the case hole pattern before
battery_pack | battery | link trunk | 95.0 g Removable 2S 18650 pack, 65 x 37 x 19 mm class, 7.4 V ~3000 mAh; slide
compute_board | electronics link trunk | 30.0 g Single-board computer up to 50 x 27 mm on the trunk deck above the hip
camera_module_3 | camera | link head | 4.0 g Raspberry Pi Camera Module 3 Standard class, 25 x 24 mm board

# MICRO X Rev C / left_yaw2roll

link: left_yaw2roll | millimetres | original design, prototype reference, not production released

SIDE X-Z

Overall: 32.40 x 40.40 mm

TOP X-Y

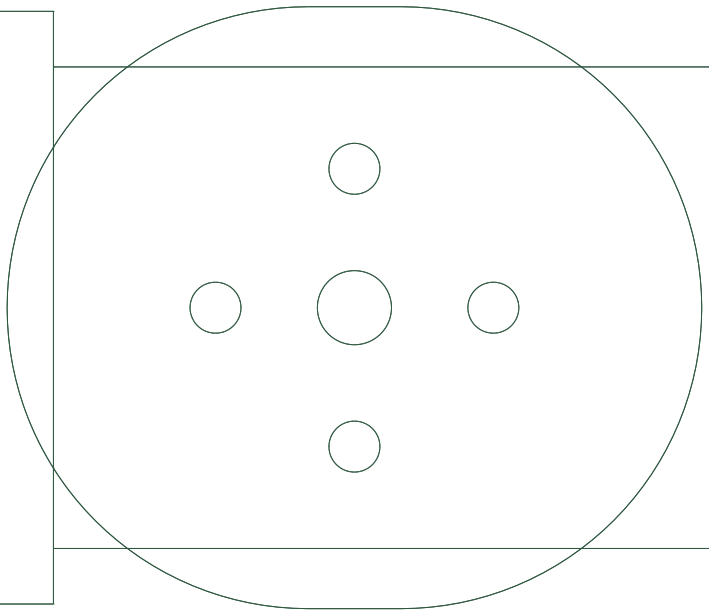
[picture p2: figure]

Overall: 32.40 x 26.80 mm

FRONT Y-Z

Overall: 26.80 x 40.40 mm

Assembly-frame extents X/Y/Z: 32.4 / 26.8 / 40.4 mm
Material volume: 13731.2 mm3 | PLA solid-equivalent: 17.03 g (slicer mass will be lower)

Hip yaw horn plate on a U-channel around the hip roll servo. Print on the plate face; every wall is vertical.
Use STEP for exact geometry. Clearance, fastening, interference and physical fit require prototype verification. Rights: root LICENSE.

# MICRO X Rev C / left_hip

link: left_hip | millimetres | original design, prototype reference, not production released

SIDE X-Z

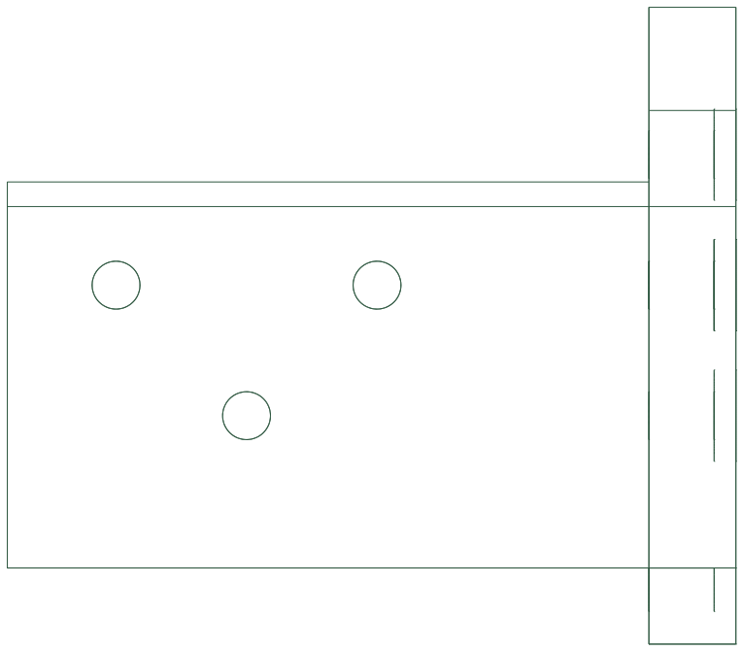
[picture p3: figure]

Overall: 33.50 x 29.27 mm

TOP X-Y

Overall: 33.50 x 38.10 mm

FRONT Y-Z

Overall: 38.10 x 29.27 mm

Assembly-frame extents X/Y/Z: 33.5 / 38.1 / 29.27 mm
Material volume: 5061.1 mm3 | PLA solid-equivalent: 6.28 g (slicer mass will be lower)

Hip corner bracket: roll horn plate and pitch horn plate joined by one rib. Print on the pitch plate face.
Use STEP for exact geometry. Clearance, fastening, interference and physical fit require prototype verification. Rights: root LICENSE.

# MICRO X Rev C / left_upper_leg

link: left_upper_leg | millimetres | original design, prototype reference, not production released

SIDE X-Z

Overall: 62.20 x 44.50 mm

TOP X-Y

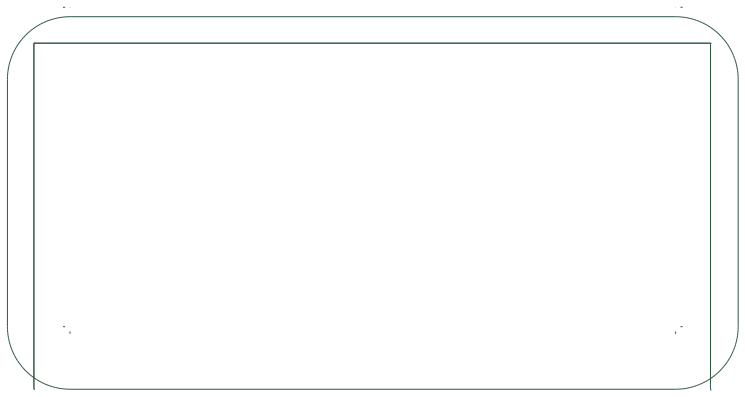
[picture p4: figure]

Overall: 62.20 x 31.75 mm

FRONT Y-Z

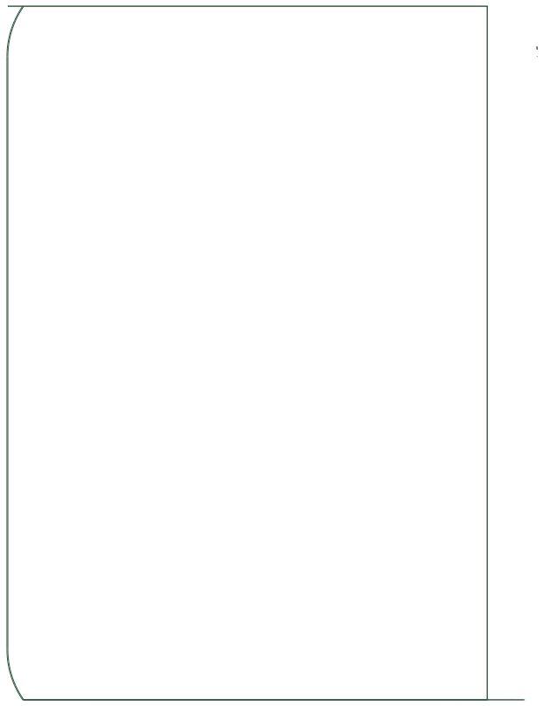
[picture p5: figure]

Overall: 31.75 x 44.50 mm

Assembly-frame extents X/Y/Z: 62.2 / 31.75 / 44.5 mm
Material volume: 18593.5 mm3 | PLA solid-equivalent: 23.06 g (slicer mass will be lower)

Thigh shell around the hip pitch and knee servos, open on the inboard face. Print on the outboard face; the cavity opens upward, no support. Use STEP for exact geometry. Clearance, fastening, interference and physical fit require prototype verification. Rights: root LICENSE.

# MICRO X Rev C / left_lower_leg

link: left_lower_leg | millimetres | original design, prototype reference, not production released

SIDE X-Z

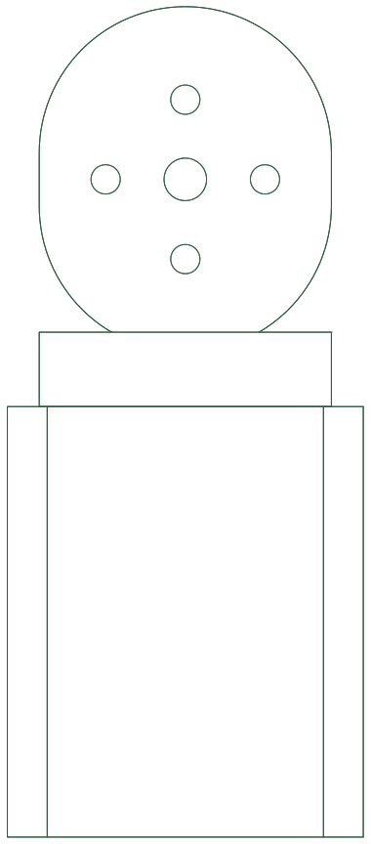
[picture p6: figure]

Overall: 26.80 x 62.50 mm

TOP X-Y

Overall: 26.80 x 14.40 mm

FRONT Y-Z

Overall: 14.40 x 62.50 mm

Assembly-frame extents X/Y/Z: 26.8 / 14.4 / 62.5 mm
Material volume: 6898.7 mm3 | PLA solid-equivalent: 8.55 g (slicer mass will be lower)

Shin: knee horn plate stepping down into a channel around the ankle servo. Print on the inboard face.
Use STEP for exact geometry. Clearance, fastening, interference and physical fit require prototype verification. Rights: root LICENSE.

# MICRO X Rev C / left_foot

link: left_foot | millimetres | original design, prototype reference, not production released

SIDE X-Z

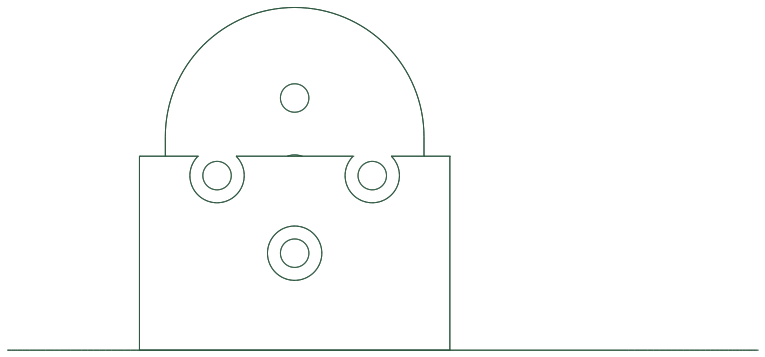
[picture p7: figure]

Overall: 58.00 x 38.00 mm

TOP X-Y

Overall: 58.00 x 46.00 mm

FRONT Y-Z

Overall: 46.00 x 38.00 mm

Assembly-frame extents X/Y/Z: 58.0 / 46.0 / 38.0 mm
Material volume: 20113.1 mm3 | PLA solid-equivalent: 24.94 g (slicer mass will be lower)

Foot: ankle horn plate on a wide rounded sole, hollow underneath for a replaceable pad. Print sole down.
Use STEP for exact geometry. Clearance, fastening, interference and physical fit require prototype verification. Rights: root LICENSE.

# MICRO X Rev C / right_yaw2roll

link: right_yaw2roll | millimetres | original design, prototype reference, not production released

SIDE X-Z

Overall: 32.40 x 40.40 mm

TOP X-Y

Overall: 32.40 x 26.80 mm

FRONT Y-Z

Overall: 26.80 x 40.40 mm

Assembly-frame extents X/Y/Z: 32.4 / 26.8 / 40.4 mm
Material volume: 13731.2 mm3 | PLA solid-equivalent: 17.03 g (slicer mass will be lower)

Hip yaw horn plate on a U-channel around the hip roll servo. Print on the plate face; every wall is vertical.
Use STEP for exact geometry. Clearance, fastening, interference and physical fit require prototype verification. Rights: root LICENSE.

# MICRO X Rev C / right_hip

link: right_hip | millimetres | original design, prototype reference, not production released

SIDE X-Z

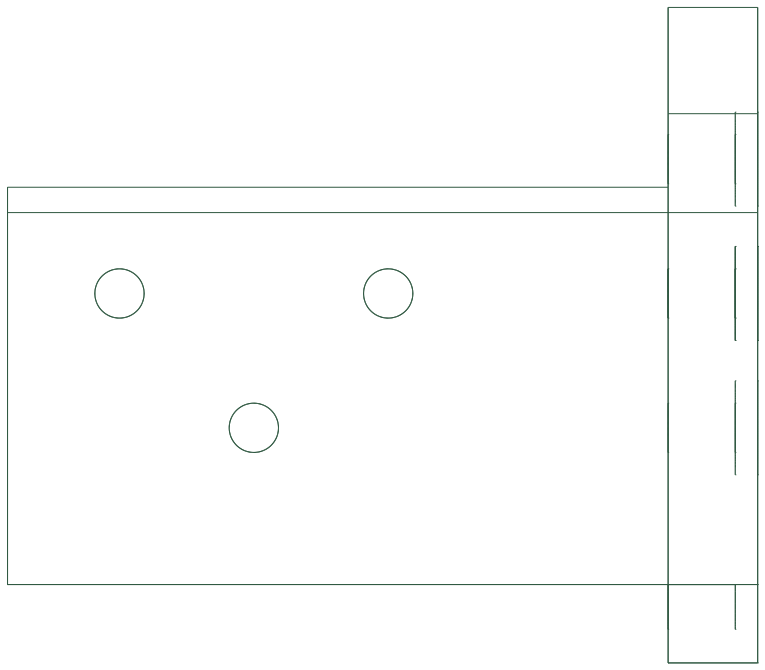
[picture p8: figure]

Overall: 33.50 x 29.27 mm

TOP X-Y

Overall: 33.50 x 38.10 mm

FRONT Y-Z

Overall: 38.10 x 29.27 mm

Assembly-frame extents X/Y/Z: 33.5 / 38.1 / 29.27 mm
Material volume: 5061.1 mm3 | PLA solid-equivalent: 6.28 g (slicer mass will be lower)

Hip corner bracket: roll horn plate and pitch horn plate joined by one rib. Print on the pitch plate face.
Use STEP for exact geometry. Clearance, fastening, interference and physical fit require prototype verification. Rights: root LICENSE.

# MICRO X Rev C / right_upper_leg

link: right_upper_leg | millimetres | original design, prototype reference, not production released

SIDE X-Z

Overall: 62.20 x 44.50 mm

TOP X-Y

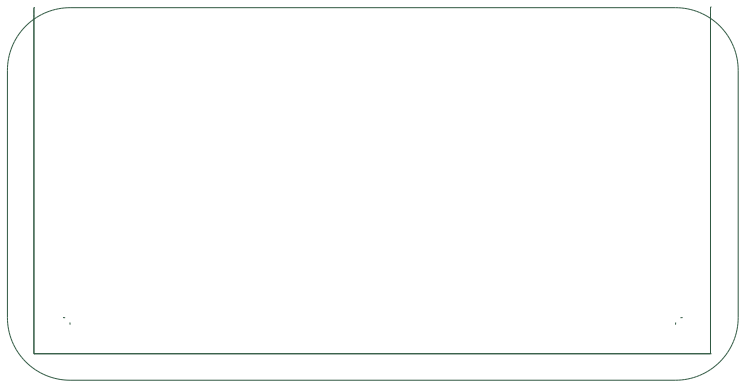
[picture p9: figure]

Overall: 62.20 x 31.75 mm

FRONT Y-Z

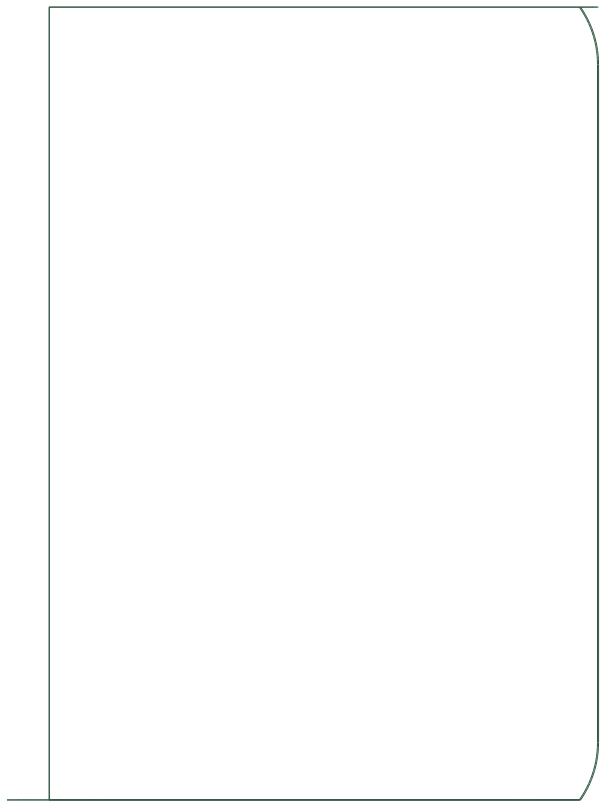
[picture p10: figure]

Overall: 31.75 x 44.50 mm

Assembly-frame extents X/Y/Z: 62.2 / 31.75 / 44.5 mm
Material volume: 18593.5 mm3 | PLA solid-equivalent: 23.06 g (slicer mass will be lower)

Thigh shell around the hip pitch and knee servos, open on the inboard face. Print on the outboard face; the cavity opens upward, no support. Use STEP for exact geometry. Clearance, fastening, interference and physical fit require prototype verification. Rights: root LICENSE.

# MICRO X Rev C / right_lower_leg

link: right_lower_leg | millimetres | original design, prototype reference, not production released

SIDE X-Z

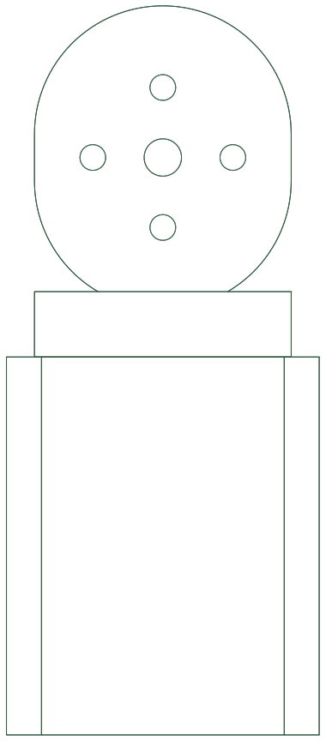
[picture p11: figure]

Overall: 26.80 x 62.50 mm

TOP X-Y

Overall: 26.80 x 14.40 mm

FRONT Y-Z

Overall: 14.40 x 62.50 mm

Assembly-frame extents X/Y/Z: 26.8 / 14.4 / 62.5 mm
Material volume: 6898.7 mm3 | PLA solid-equivalent: 8.55 g (slicer mass will be lower)

Shin: knee horn plate stepping down into a channel around the ankle servo. Print on the inboard face.
Use STEP for exact geometry. Clearance, fastening, interference and physical fit require prototype verification. Rights: root LICENSE.

# MICRO X Rev C / right_foot

link: right_foot | millimetres | original design, prototype reference, not production released

SIDE X-Z

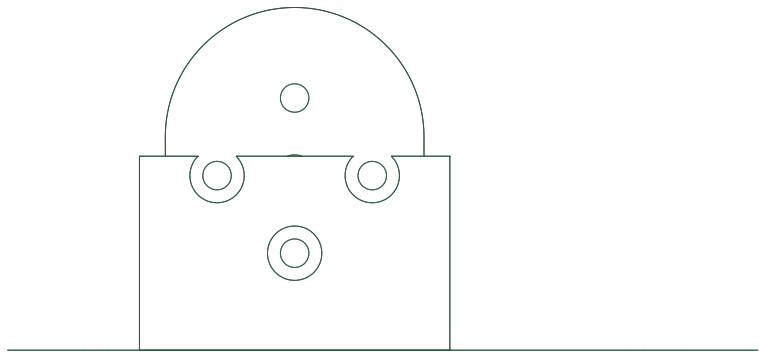
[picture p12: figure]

Overall: 58.00 x 38.00 mm

TOP X-Y

Overall: 58.00 x 46.00 mm

FRONT Y-Z

Overall: 46.00 x 38.00 mm

Assembly-frame extents X/Y/Z: 58.0 / 46.0 / 38.0 mm
Material volume: 20113.1 mm3 | PLA solid-equivalent: 24.94 g (slicer mass will be lower)

Foot: ankle horn plate on a wide rounded sole, hollow underneath for a replaceable pad. Print sole down.
Use STEP for exact geometry. Clearance, fastening, interference and physical fit require prototype verification. Rights: root LICENSE.

# MICRO X Rev C / chassis

link: trunk | millimetres | original design, prototype reference, not production released

SIDE X-Z

Overall: 131.00 x 51.90 mm

TOP X-Y

Overall: 131.00 x 61.98 mm

FRONT Y-Z

Overall: 61.98 x 51.90 mm

Assembly-frame extents X/Y/Z: 131.0 / 61.98 / 51.9 mm
Material volume: 35870.4 mm3 | PLA solid-equivalent: 44.48 g (slicer mass will be lower)

Chassis: floor with two hip-yaw servo boxes, neck horn plate, battery tray and compute board wall. Print floor down; the servo boxes bridge 21 mm. Use STEP for exact geometry. Clearance, fastening, interference and physical fit require prototype verification. Rights: root LICENSE.

# MICRO X Rev C / torso_shell

link: trunk | millimetres | original design, prototype reference, not production released

SIDE X-Z

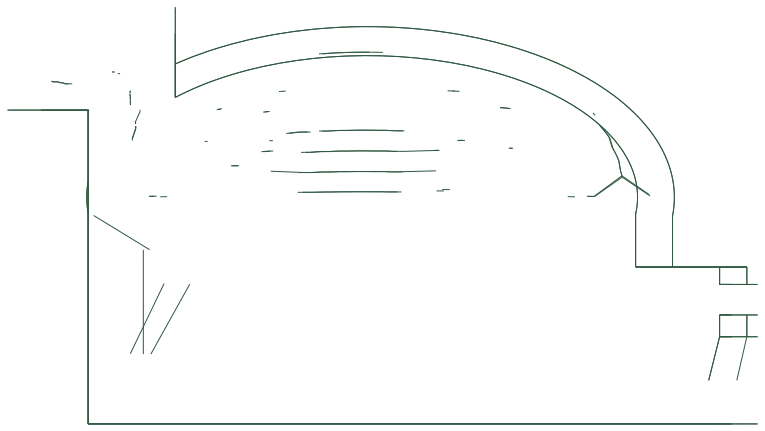
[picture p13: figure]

Overall: 86.04 x 47.80 mm

TOP X-Y

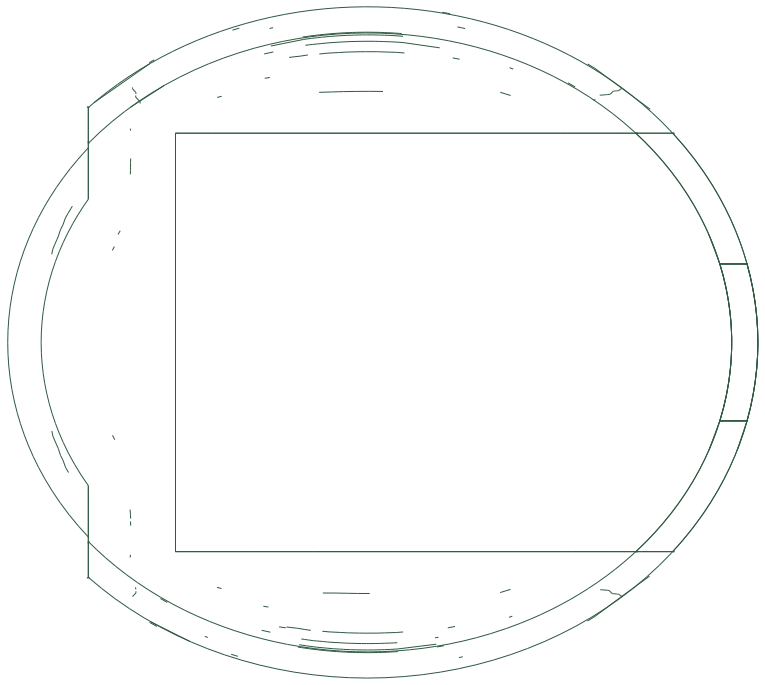
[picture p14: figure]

Overall: 86.04 x 77.20 mm

FRONT Y-Z

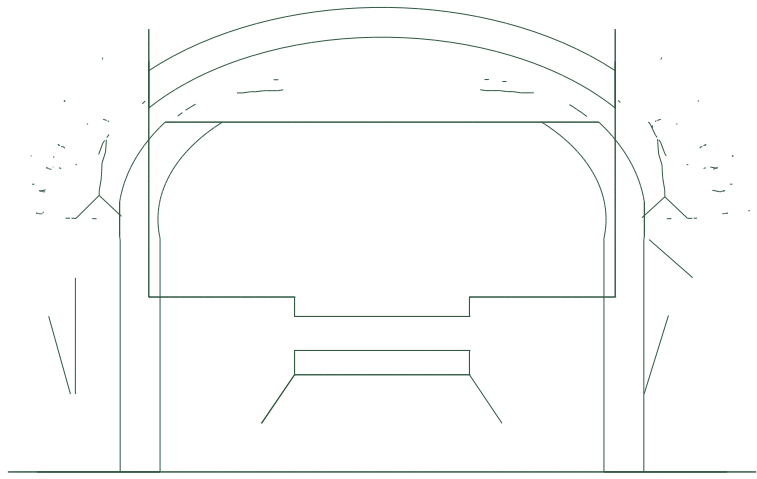
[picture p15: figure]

Overall: 77.20 x 47.80 mm

Assembly-frame extents X/Y/Z: 86.04 / 77.2 / 47.8 mm
Material volume: 23445.0 mm3 | PLA solid-equivalent: 29.07 g (slicer mass will be lower)

One-piece egg shell with a chest grille, neck slot and tail opening, open under the hips. Four M3 through the flanks into chassis bosses. Use STEP for exact geometry. Clearance, fastening, interference and physical fit require prototype verification. Rights: root LICENSE.

# MICRO X Rev C / tail_cover

link: trunk | millimetres | original design, prototype reference, not production released

SIDE X-Z

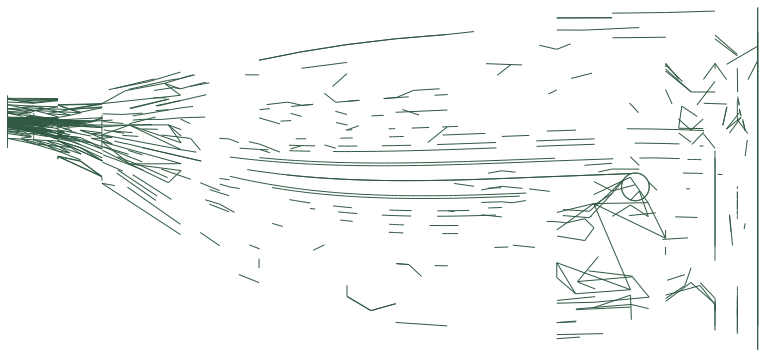
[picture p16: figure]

Overall: 92.00 x 41.99 mm

TOP X-Y

Overall: 92.00 x 64.00 mm

FRONT Y-Z

Overall: 64.00 x 41.99 mm

Assembly-frame extents X/Y/Z: 92.0 / 64.0 / 41.99 mm
Material volume: 31514.7 mm3 | PLA solid-equivalent: 39.08 g (slicer mass will be lower)

Tail doubles as the battery cover: slides over the tray and takes two M3 into it.
Use STEP for exact geometry. Clearance, fastening, interference and physical fit require prototype verification. Rights: root LICENSE.

# MICRO X Rev C / neck_link

link: neck | millimetres | original design, prototype reference, not production released

SIDE X-Z

Overall: 24.80 x 71.70 mm

TOP X-Y

Overall: 24.80 x 31.40 mm

FRONT Y-Z

Overall: 31.40 x 71.70 mm

Assembly-frame extents X/Y/Z: 24.8 / 31.4 / 71.7 mm
Material volume: 12901.6 mm3 | PLA solid-equivalent: 16.0 g (slicer mass will be lower)

Neck tube around the stacked neck-pitch and head-pitch servos, open on the horn side. Print on the closed face.
Use STEP for exact geometry. Clearance, fastening, interference and physical fit require prototype verification. Rights: root LICENSE.

# MICRO X Rev C / neck_sleeve

link: neck | millimetres | original design, prototype reference, not production released

SIDE X-Z

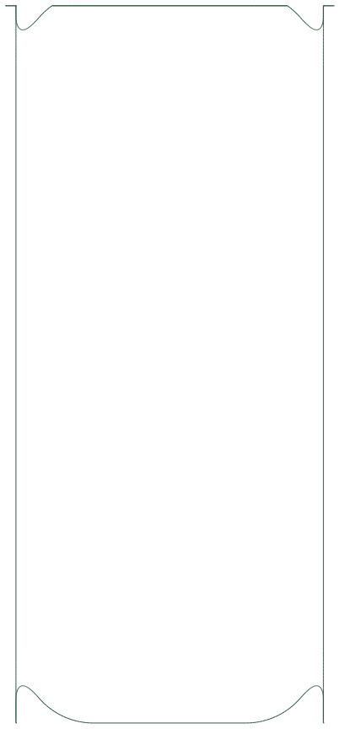
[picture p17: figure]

Overall: 31.00 x 61.12 mm

TOP X-Y

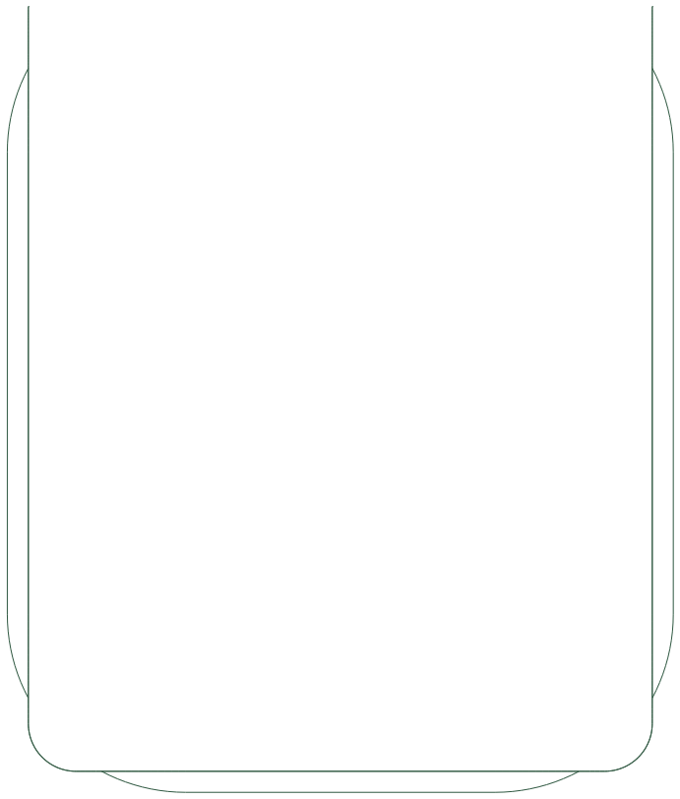
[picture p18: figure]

Overall: 31.00 x 34.52 mm

FRONT Y-Z

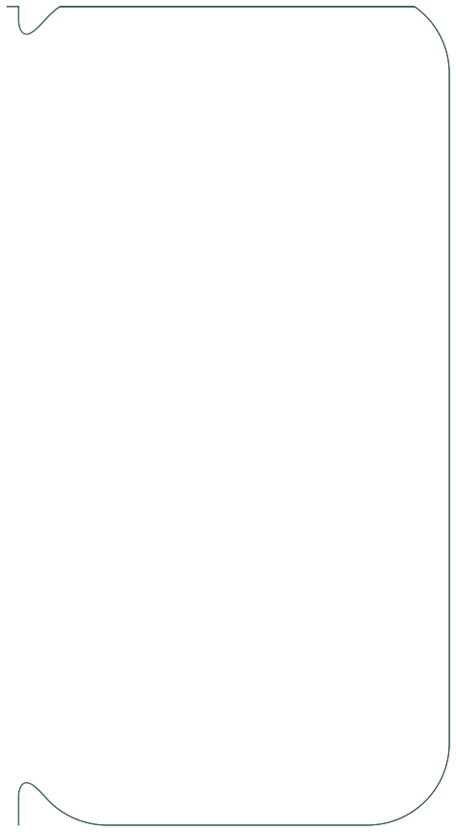
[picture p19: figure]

Overall: 34.52 x 61.12 mm

Assembly-frame extents X/Y/Z: 31.0 / 34.52 / 61.12 mm
Material volume: 10780.1 mm3 | PLA solid-equivalent: 13.37 g (slicer mass will be lower)

Neck cover: rounded shell over the neck column, open on the horn side; pitches with the neck.
Use STEP for exact geometry. Clearance, fastening, interference and physical fit require prototype verification. Rights: root LICENSE.

# MICRO X Rev C / head_base

link: head_base | millimetres | original design, prototype reference, not production released

SIDE X-Z

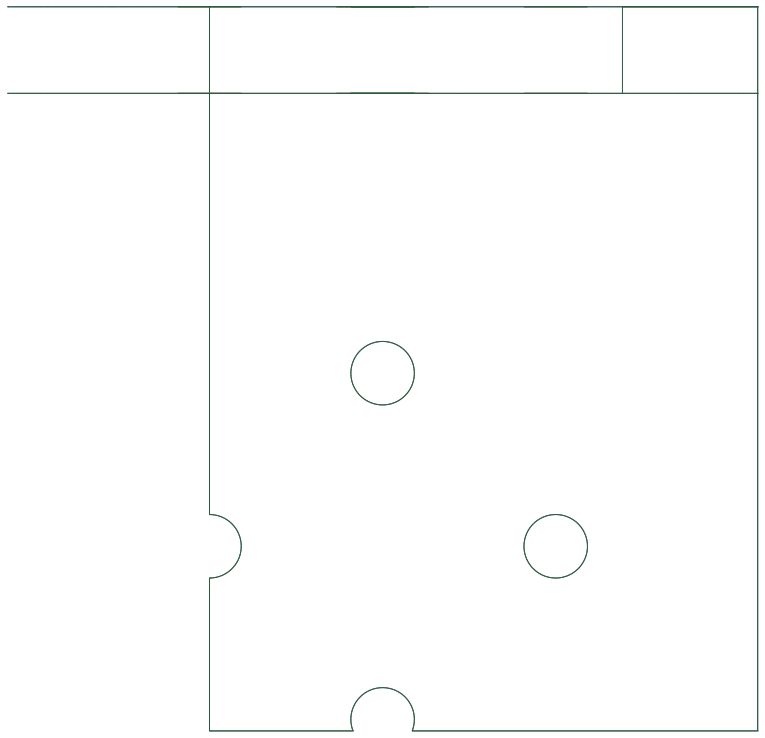
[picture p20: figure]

Overall: 26.00 x 25.10 mm

TOP X-Y

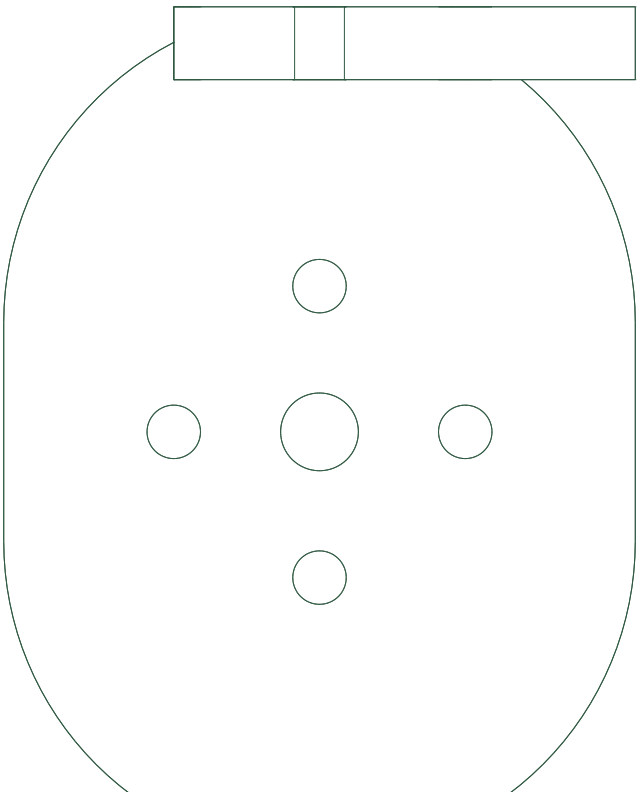
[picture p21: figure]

Overall: 26.00 x 35.00 mm

FRONT Y-Z

Overall: 35.00 x 25.10 mm

Assembly-frame extents X/Y/Z: 26.0 / 35.0 / 25.1 mm
Material volume: 3523.0 mm3 | PLA solid-equivalent: 4.37 g (slicer mass will be lower)

Head base: head-pitch horn plate joined to the head-yaw horn plate. The only part that stays still while the head yaws.
Use STEP for exact geometry. Clearance, fastening, interference and physical fit require prototype verification. Rights: root LICENSE.

# MICRO X Rev C / head_yoke

link: head_yoke | millimetres | original design, prototype reference, not production released

SIDE X-Z

Overall: 31.30 x 32.40 mm

TOP X-Y

Overall: 31.30 x 37.80 mm

FRONT Y-Z

Overall: 37.80 x 32.40 mm

Assembly-frame extents X/Y/Z: 31.3 / 37.8 / 32.4 mm
Material volume: 12429.4 mm3 | PLA solid-equivalent: 15.41 g (slicer mass will be lower)

Yoke: box around the head-yaw servo with two ribs out to the head-roll horn plate.
Use STEP for exact geometry. Clearance, fastening, interference and physical fit require prototype verification. Rights: root LICENSE.

# MICRO X Rev C / head_frame

link: head | millimetres | original design, prototype reference, not production released

SIDE X-Z

Overall: 94.20 x 41.70 mm

TOP X-Y

Overall: 94.20 x 61.90 mm

FRONT Y-Z

Overall: 61.90 x 41.70 mm

Assembly-frame extents X/Y/Z: 94.2 / 61.9 / 41.7 mm
Material volume: 20656.8 mm3 | PLA solid-equivalent: 25.61 g (slicer mass will be lower)

Head frame: one shell with a deck over the yoke, the head-roll and jaw servo bays, a forward beam, the camera wall and three skull bosses. Use STEP for exact geometry. Clearance, fastening, interference and physical fit require prototype verification. Rights: root LICENSE.

# MICRO X Rev C / skull

link: head | millimetres | original design, prototype reference, not production released

SIDE X-Z

Overall: 134.00 x 54.77 mm

TOP X-Y

Overall: 134.00 x 110.20 mm

FRONT Y-Z

Overall: 110.20 x 54.77 mm

Assembly-frame extents X/Y/Z: 134.0 / 110.2 / 54.77 mm
Material volume: 62863.3 mm3 | PLA solid-equivalent: 77.95 g (slicer mass will be lower)

Head: one-piece round hollow shell with a short bill, camera ring and nostrils. Three M3 down into the head frame; the eyes are painted, not parts. Use STEP for exact geometry. Clearance, fastening, interference and physical fit require prototype verification. Rights: root LICENSE.

# MICRO X Rev C / jaw_beak

link: jaw | millimetres | original design, prototype reference, not production released

SIDE X-Z

Overall: 62.00 x 34.00 mm

TOP X-Y

Overall: 62.00 x 65.97 mm

FRONT Y-Z

Overall: 65.97 x 34.00 mm

Assembly-frame extents X/Y/Z: 62.0 / 65.97 / 34.0 mm
Material volume: 8948.4 mm3 | PLA solid-equivalent: 11.1 g (slicer mass will be lower)

Lower bill: wide rounded scoop on a single arm bolted to the jaw servo horn.
Use STEP for exact geometry. Clearance, fastening, interference and physical fit require prototype verification. Rights: root LICENSE.

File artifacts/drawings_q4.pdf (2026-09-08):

# MICRO X Q4 / torso_lower

P0 independent appearance / assembly prototype | millimetres | not production released

SIDE X-Z

Overall: 111.00 x 56.99 mm

TOP X-Y

Overall: 111.00 x 88.00 mm

FRONT Y-Z

Overall: 88.00 x 56.99 mm

Model dimensions X/Y/Z: 111.0 / 88.0 / 56.99 mm
Material volume: 49715.43 mm3 | PLA solid-equivalent: 61.65 g (not slicer mass)

Shared Micro X P0 geometry; drive integration not complete.
Use STEP for exact geometry. Overall views do not constitute full production GD&T.
Clearance, fastening, interference and physical fit require prototype verification. Rights: root LICENSE.

# MICRO X Q4 / torso_upper

SIDE X-Z

Overall: 103.69 x 33.00 mm

TOP X-Y

Overall: 103.69 x 79.05 mm

FRONT Y-Z

Overall: 79.05 x 33.00 mm

Model dimensions X/Y/Z: 103.69 / 79.05 / 33.0 mm
Material volume: 26630.22 mm3 | PLA solid-equivalent: 33.02 g (not slicer mass)

Shared Micro X P0 geometry; drive integration not complete.
Use STEP for exact geometry. Overall views do not constitute full production GD&T.
Clearance, fastening, interference and physical fit require prototype verification. Rights: root LICENSE.

# MICRO X Q4 / neck_cradle

SIDE X-Z

Overall: 20.00 x 51.00 mm

TOP X-Y

Overall: 20.00 x 24.00 mm

FRONT Y-Z

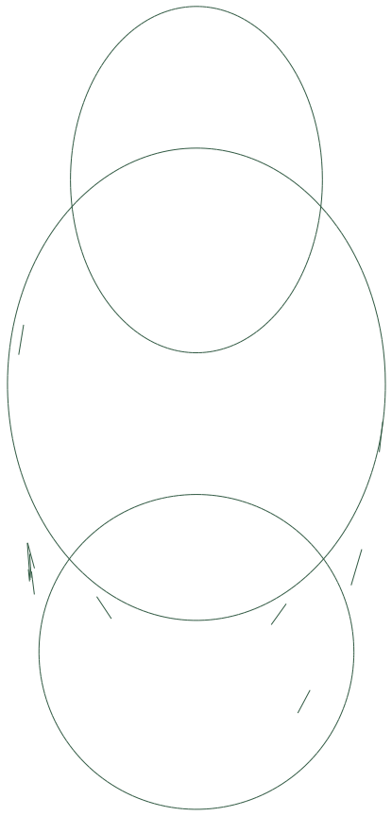
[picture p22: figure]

Overall: 24.00 x 51.00 mm

Model dimensions X/Y/Z: 20.0 / 24.0 / 51.0 mm
Material volume: 8493.82 mm3 | PLA solid-equivalent: 10.53 g (not slicer mass)

Shared Micro X P0 geometry; drive integration not complete.
Use STEP for exact geometry. Overall views do not constitute full production GD&T.
Clearance, fastening, interference and physical fit require prototype verification. Rights: root LICENSE.

# MICRO X Q4 / eye_left

SIDE X-Z

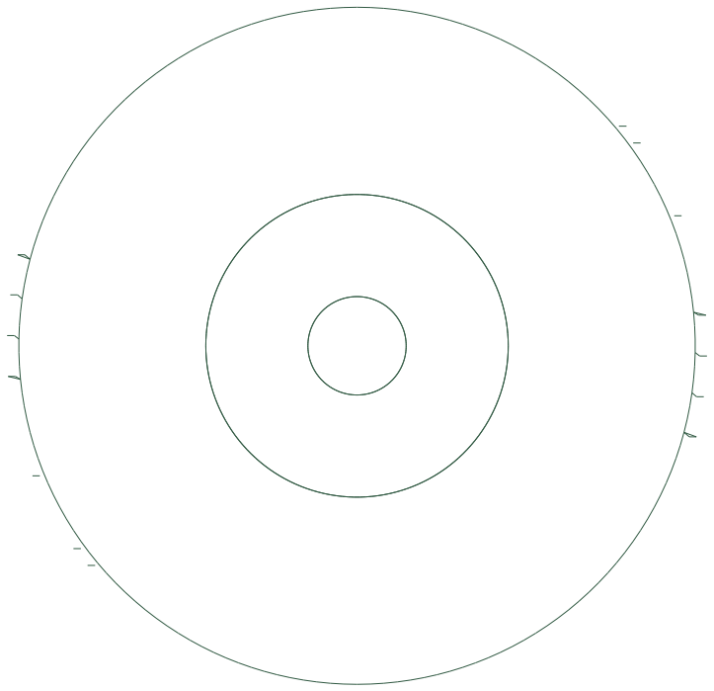
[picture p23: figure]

Overall: 19.60 x 19.60 mm

TOP X-Y

Overall: 19.60 x 19.80 mm

FRONT Y-Z

Overall: 19.80 x 19.60 mm

Model dimensions X/Y/Z: 19.6 / 19.8 / 19.6 mm
Material volume: 3375.51 mm3 | PLA solid-equivalent: 4.19 g (not slicer mass)

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

# MICRO X Q4 / eye_right

SIDE X-Z

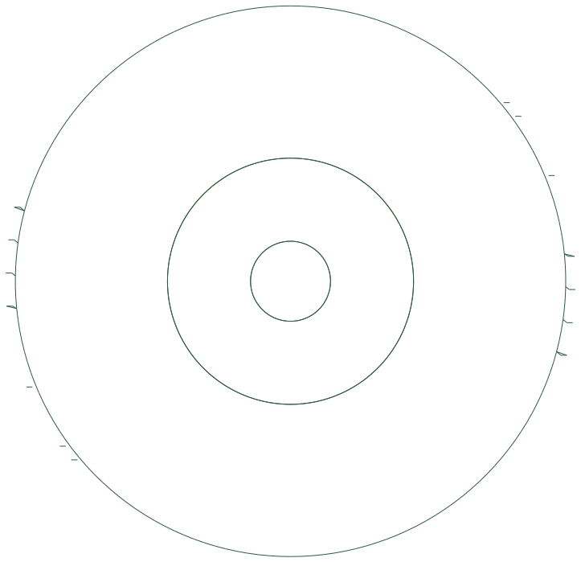
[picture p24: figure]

Overall: 19.60 x 19.60 mm

TOP X-Y

Overall: 19.60 x 19.80 mm

FRONT Y-Z

Overall: 19.80 x 19.60 mm

Model dimensions X/Y/Z: 19.6 / 19.8 / 19.6 mm
Material volume: 3375.51 mm3 | PLA solid-equivalent: 4.19 g (not slicer mass)

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

# MICRO X Q4 / camera_carrier

SIDE X-Z

Overall: 10.50 x 26.75 mm

TOP X-Y

Overall: 10.50 x 29.00 mm

FRONT Y-Z

Overall: 29.00 x 26.75 mm

Model dimensions X/Y/Z: 10.5 / 29.0 / 26.75 mm
Material volume: 1272.97 mm3 | PLA solid-equivalent: 1.58 g (not slicer mass)

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

# MICRO X Q4 / skull

SIDE X-Z

Overall: 112.00 x 61.00 mm

TOP X-Y

Overall: 112.00 x 70.00 mm

FRONT Y-Z

Overall: 70.00 x 61.00 mm

Model dimensions X/Y/Z: 112.0 / 70.0 / 61.0 mm
Material volume: 42721.38 mm3 | PLA solid-equivalent: 52.97 g (not slicer mass)

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

# MICRO X Q4 / jaw

SIDE X-Z

Overall: 104.00 x 20.98 mm

TOP X-Y

Overall: 104.00 x 70.00 mm

FRONT Y-Z

Overall: 70.00 x 20.98 mm

Model dimensions X/Y/Z: 104.0 / 70.0 / 20.98 mm
Material volume: 31832.39 mm3 | PLA solid-equivalent: 39.47 g (not slicer mass)

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

# MICRO X Q4 / tail_left

SIDE X-Z

Overall: 147.00 x 47.00 mm

TOP X-Y

Overall: 147.00 x 17.00 mm

FRONT Y-Z

Overall: 17.00 x 47.00 mm

Model dimensions X/Y/Z: 147.0 / 17.0 / 47.0 mm
Material volume: 10732.75 mm3 | PLA solid-equivalent: 13.31 g (not slicer mass)

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

# MICRO X Q4 / tail_right

SIDE X-Z

Overall: 147.00 x 47.00 mm

TOP X-Y

Overall: 147.00 x 17.00 mm

FRONT Y-Z

Overall: 17.00 x 47.00 mm

Model dimensions X/Y/Z: 147.0 / 17.0 / 47.0 mm
Material volume: 10732.75 mm3 | PLA solid-equivalent: 13.31 g (not slicer mass)

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

# MICRO X Q4 / front_hindleg_left

SIDE X-Z

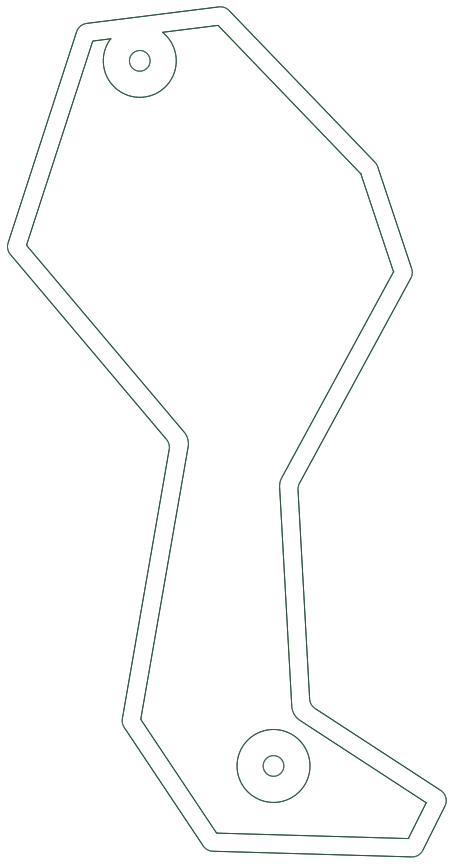
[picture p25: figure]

Overall: 72.17 x 139.86 mm

TOP X-Y

Overall: 72.17 x 18.00 mm

FRONT Y-Z

Overall: 18.00 x 139.86 mm

Model dimensions X/Y/Z: 72.17 / 18.0 / 139.86 mm
Material volume: 39972.86 mm3 | PLA solid-equivalent: 49.57 g (not slicer mass)

Repeated fixed leg/foot for packaging; powered leg cartridge not yet integrated.
Use STEP for exact geometry. Overall views do not constitute full production GD&T.
Clearance, fastening, interference and physical fit require prototype verification. Rights: root LICENSE.

# MICRO X Q4 / front_foot_left

SIDE X-Z

Overall: 80.50 x 26.00 mm

TOP X-Y


Overall: 80.50 x 42.00 mm

FRONT Y-Z

Overall: 42.00 x 26.00 mm

Model dimensions X/Y/Z: 80.5 / 42.0 / 26.0 mm
Material volume: 26306.25 mm3 | PLA solid-equivalent: 32.62 g (not slicer mass)

Repeated fixed leg/foot for packaging; powered leg cartridge not yet integrated.
Use STEP for exact geometry. Overall views do not constitute full production GD&T.
Clearance, fastening, interference and physical fit require prototype verification. Rights: root LICENSE.

# MICRO X Q4 / front_hindleg_right

SIDE X-Z

Overall: 72.17 x 139.86 mm

TOP X-Y

Overall: 72.17 x 18.00 mm

FRONT Y-Z

Overall: 18.00 x 139.86 mm

Model dimensions X/Y/Z: 72.17 / 18.0 / 139.86 mm
Material volume: 39972.86 mm3 | PLA solid-equivalent: 49.57 g (not slicer mass)

Repeated fixed leg/foot for packaging; powered leg cartridge not yet integrated.
Use STEP for exact geometry. Overall views do not constitute full production GD&T.
Clearance, fastening, interference and physical fit require prototype verification. Rights: root LICENSE.

# MICRO X Q4 / front_foot_right

SIDE X-Z

Overall: 80.50 x 26.00 mm

TOP X-Y

Overall: 80.50 x 42.00 mm

FRONT Y-Z

Overall: 42.00 x 26.00 mm

Model dimensions X/Y/Z: 80.5 / 42.0 / 26.0 mm
Material volume: 26306.25 mm3 | PLA solid-equivalent: 32.62 g (not slicer mass)

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

# MICRO X Q4 / rear_hindleg_left

SIDE X-Z

Overall: 72.17 x 139.86 mm

TOP X-Y

Overall: 72.17 x 18.00 mm

FRONT Y-Z

Overall: 18.00 x 139.86 mm

Model dimensions X/Y/Z: 72.17 / 18.0 / 139.86 mm
Material volume: 39972.86 mm3 | PLA solid-equivalent: 49.57 g (not slicer mass)

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

# MICRO X Q4 / rear_foot_left

SIDE X-Z

Overall: 80.50 x 26.00 mm

TOP X-Y

Overall: 80.50 x 42.00 mm

FRONT Y-Z

Overall: 42.00 x 26.00 mm

Model dimensions X/Y/Z: 80.5 / 42.0 / 26.0 mm
Material volume: 26306.25 mm3 | PLA solid-equivalent: 32.62 g (not slicer mass)

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

# MICRO X Q4 / rear_hindleg_right

SIDE X-Z

Overall: 72.17 x 139.86 mm

TOP X-Y

Overall: 72.17 x 18.00 mm

FRONT Y-Z

Overall: 18.00 x 139.86 mm

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

# MICRO X Q4 / rear_foot_right

SIDE X-Z

Overall: 80.50 x 26.00 mm

TOP X-Y


Overall: 80.50 x 42.00 mm

FRONT Y-Z

Overall: 42.00 x 26.00 mm

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

# MICRO X Q4 / side_rail_left

SIDE X-Z

Overall: 128.00 x 16.00 mm

TOP X-Y

Overall: 128.00 x 5.40 mm

FRONT Y-Z

Overall: 5.40 x 16.00 mm

Model dimensions X/Y/Z: 128.0 / 5.4 / 16.0 mm
Material volume: 8300.17 mm3 | PLA solid-equivalent: 10.29 g (not slicer mass)

M3 axes X=-60/-14/50 Z143. Pilot packaging rail; anti-rotation and joint bearing stack unresolved.
Use STEP for exact geometry. Overall views do not constitute full production GD&T.
Clearance, fastening, interference and physical fit require prototype verification. Rights: root LICENSE.

# MICRO X Q4 / side_rail_right

SIDE X-Z

Overall: 128.00 x 16.00 mm

TOP X-Y

Overall: 128.00 x 5.40 mm

FRONT Y-Z

Overall: 5.40 x 16.00 mm

Model dimensions X/Y/Z: 128.0 / 5.4 / 16.0 mm
Material volume: 8300.17 mm3 | PLA solid-equivalent: 10.29 g (not slicer mass)

M3 axes X=-60/-14/50 Z143. Pilot packaging rail; anti-rotation and joint bearing stack unresolved.
Use STEP for exact geometry. Overall views do not constitute full production GD&T.
Clearance, fastening, interference and physical fit require prototype verification. Rights: root LICENSE.

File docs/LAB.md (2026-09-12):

# Micro X Lab

[Lab 열기](https://hwkim3330.github.io/micro-x/web/lab.html) · [보행 실험](https://hwkim3330.github.io/micro-x/web/simulator.html)

Lab은 Rev A CAD 위에서 **구조 탐색 → 14축 학습 → 평가 → 재생**이 한 화면에서 이어지도록 만들었습니다. 무거운 계산(MuJoCo·BAM·PyTorch)은 로컬 서버가 하고, 공개 페이지는 저장소에 고정된 기록을 보여 줍니다.

## 탭 구성

| 탭 | 공개 페이지 | 로컬 서버 연결 시 |
|---|---|---|
| 구조 | 레이어별 부품 표시, 치수·질량·STL/STEP | 동일 |
| 14축 학습 | 공식 가중치·이어 학습·500회 학습 기록 카드 | 이름·업데이트·스텝·시드로 **실제 PPO 실행**, 업데이트별 평균 보상·넘어짐 그래프, 체크포인트 목록, **평가 실행**과 결과 표, ONNX 저장 |
| 보행 재생 | 공식 가중치로 계산한 qpos 기록을 실제 CAD 관절에 재생, 관절 각도 표시 | 동일 |
| 1축 실습 | 브라우저 CEM으로 가상 턱 서보 계수 학습, 저장/불러오기 | 동일 |
| 목소리 | 브라우저 TTS와 턱 애니메이션 | 동일 |

## 로컬 서버 실행

```sh
uv venv --python 3.12 .venv-policy
uv pip install --python .venv-policy/bin/python -r requirements-policy.txt
.venv-policy/bin/python tools/fetch_compat.py        # 공식 추론 코드·가중치를 .cache/compat에 내려받고 SHA256 검증
.venv-policy/bin/python runtime/training_service.py  # http://127.0.0.1:5201/web/lab.html
```

BAM 액추에이터 패키지는 Python 3.12를 요구합니다. 서버는 루프백에만 바인딩하고, 다른 출처의 요청·경로 탈출·HEAD·잘못된 설정을 거부합니다.

## API

| 엔드포인트 | 설명 |
|---|---|
| `POST /api/train {name, updates, steps, seed}` | `tools/train_compat.py` 실행. 진행은 `.cache/checkpoints/progress.json` |
| `GET /api/progress` | 업데이트별 평균 보상·넘어짐·손실 |
| `GET /api/checkpoints` | 저장된 ONNX와 학습 요약, 평가 여부 |
| `POST /api/evaluate {checkpoint, seconds, seeds}` | `tools/evaluate_compat.py`를 시드 10부터, 정지·전진 0.1/0.3·회전 0.3 명령으로 실행 |
| `GET /api/evaluation/<name>` | 평가 결과 (`official` 또는 체크포인트 이름) |
| `GET /api/checkpoint?name=<name>` | ONNX 다운로드 |
| `POST /api/sim/start {seed, policy}` / `POST /api/sim/step` | 공식 또는 체크포인트 정책으로 실시간 시뮬레이션. 응답에 전체 `qpos`가 포함되어 브라우저가 실제 CAD 리그를 그 자세로 놓습니다 |

## 평가 기준 (모든 정책에 동일)

1초 워밍업 후 몸체 좌표계의 전진·좌우 속도와 요 각속도를 평균해 명령과의 MAE를 계산합니다. 통과 기준은 넘어짐 없음, 전진 MAE ≤ max(0.03, 명령의 25 %), 좌우 ≤ 0.03 m/s, 요 ≤ 0.10 rad/s입니다. 이 기준은 저장소가 정한 공학적 목표이며 업계 표준이 아닙니다.

## 무엇이 아닌가

- 브라우저 안에서 14축 보행을 학습하지 않습니다. 브라우저 학습은 교육용 1축 예제만입니다.
- 학습한 정책이 실물에서 걷는다는 증거가 아닙니다. 모든 결과는 `models/micro_x_14.xml`(CAD 기반) 시뮬레이션입니다.
- 공식 가중치·코드는 저장소에 재배포하지 않고 로컬 캐시에만 둡니다(`engineering/policy_sources.json`).

## 재현과 테스트

```sh
npm ci
node --test tests/learning.test.mjs
CHROME_PATH=/path/to/chrome node tools/test-web.mjs        # 랜딩 뷰어: 리그·관절·재생·다운로드
CHROME_PATH=/path/to/chrome node tools/test-lab.mjs        # Lab: 레이어·카드·재생·1축 학습
CHROME_PATH=/path/to/chrome node tools/test-simulator.mjs  # 로컬 서버: 실시간 물리·정책 선택
CHROME_PATH=/path/to/chrome node tools/test-compat-web.mjs # 로컬 서버: PPO 실행·평가 표·취소
```

`CHROME_PATH`를 비우면 Puppeteer가 내려받은 Chrome을 사용합니다.

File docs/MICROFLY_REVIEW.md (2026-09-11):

# Microfly에서 참고할 구조

참고: [lvwerra/microfly](https://huggingface.co/spaces/lvwerra/microfly),
revision `89ba5406bb456a53b4fb6a14215216dd35a01d10`.
[README](https://huggingface.co/spaces/lvwerra/microfly/blob/89ba5406bb456a53b4fb6a14215216dd35a01d10/README.md),
[검증 기록](https://huggingface.co/spaces/lvwerra/microfly/blob/89ba5406bb456a53b4fb6a14215216dd35a01d10/VALIDATION.md),
[출처 명세](https://huggingface.co/spaces/lvwerra/microfly/blob/89ba5406bb456a53b4fb6a14215216dd35a01d10/provenance.json)를 읽고 판단했습니다. 비행체가 아니라 초파리 연결망을 Microduck의 상위 행동 제어에 연결한 브라우저 실험입니다.

## 확인한 구조

가상 감각 입력 → 단순화한 신경 활동 계산 → 전진·회전 명령 → 공식 보행 ONNX → MuJoCo 물리 계산 순서입니다. 신경 연결망의 가중치는 이 앱에서 학습하지 않습니다. 공식 정책이 균형과 걸음을 담당합니다. 신경 출력을 직접 14개 모터 목표에 연결하는 별도 경로에는 학습된 균형 제어가 없으며, 작성자의 시험에서도 넘어짐이 기록됐습니다. 이것을 생물학적으로 검증된 뇌나 학습된 자율 탐색으로 설명하지 않습니다.

X에 참고할 것은 **행동을 고르는 기능과 균형을 잡는 기능의 분리**, 실제 물리 상태에 연결된 화면, 중지·리셋·입력 차단을 확인할 수 있는 실험 방식입니다. 별도 다운로드한 원본 연결망을 실행하고 X 물리 상태를 감각 입력으로 돌려주는 실험용 어댑터를 구현했습니다. 제품용 통합 완료를 뜻하지 않습니다.

## X 적용 순서

먼저 전진·회전 명령을 추종하는 보행 정책을 확보합니다. 그 위에 카메라 인식으로 관심 대상을 선택하고 속도·회전 명령을 만드는 행동 계층을 붙입니다. 거리·방향 측정과 명령 변환은 별도 시험하고, 센서가 오래되거나 목표가 사라지면 정지 명령으로 돌아가게 합니다. 단안 카메라만으로 거리 정확도가 확보된다고 가정하지 않습니다.

뇌 시각화나 원본 로봇 외형을 제품에 복사하는 것은 현재 범위가 아닙니다. Microfly의 앱 라이선스와 포함된 로봇·뇌 조직 메시·원본 데이터의 조건은 각각 확인해야 하며, 앱 표기만으로 X의 상업용 재배포 권리를 판단하지 않습니다. 현재 X에는 Microfly의 자산·연결망·코드를 포함하지 않았습니다.

## 직접 실행한 결과

원본 Microfly 소스의 단위 검사 9개와 브라우저 검사를 실행했습니다. 원본 Microduck은 171 제어 스텝 동안 넘어지지 않고 경로 길이 0.222 m를 이동했습니다. 좌우 가상 냄새에 따른 회전 반전, 냄새 제거 시 이동 명령 정지, 연결 차단, 일시정지·리셋·모바일 검사가 통과했습니다. 직접 모터 모드는 정책 호출 0회를 확인했지만 넘어졌으므로 보행 방식으로 채택하지 않습니다.

X에는 139,255개 뉴런·2,698,236개 연결의 전체 제공 그래프를 사용했습니다. 10초씩 좌/우 목표, 냄새 없음, 시냅스 차단, 출력 연결 해제를 실행했습니다. 좌우 조건의 명령은 발생했고 차단 조건은 0이었습니다. X는 넘어지지 않았지만 순이동은 약 1 cm에 불과해 탐색·보행 합격으로 판정하지 않았습니다. 가상 냄새는 위치로 계산하며 실물 냄새 센서를 뜻하지 않습니다. 신경 가중치 학습도 하지 않았습니다.

원본 브라우저는 XML 위치 액추에이터를 사용하고 X 서버는 BAM M6를 사용합니다. 이 차이를 줄이기 위해 X에서 생성된 동일 명령을 원본 `robot_walk.xml`과 X에 같은 Python 정책/BAM 조건으로 재생했습니다. 오른쪽 목표 조건의 순이동은 원본 약 0.439 m, X 약 0.012 m였고 양쪽 모두 넘어지지 않았습니다. 왼쪽 조건은 양쪽 약 0.011 m에 머물렀습니다. 이 결과는 X 보행 차이가 남는다는 증거이며 단일 부품을 원인으로 특정하지 않습니다. 원본 비교 XML은 브라우저의 `robot_allcollisions.xml`과 다르고, 한 시드의 명령 재생이므로 원본의 독립적인 냄새 탐색 시험도 아닙니다.

- [X 전체 신경망 실행 기록](../artifacts/fly_brain_x_evaluation.json)
- [동일 명령·BAM 비교 기록](../artifacts/fly_brain_paired_replay.json)
- [원본 브라우저 실행 요약](../artifacts/microfly_reference_validation.json)

### 재현

기존 정책 의존성을 설치한 뒤, 위에 고정한 Microfly revision의 `flyduck-source.zip`을 별도 폴더에 풉니다. 어댑터는 실행할 신경 코드와 데이터의 SHA-256을 검사합니다. 원본 로봇 자산은 X 저장소에 포함하지 않습니다.

```sh
node tools/evaluate_fly_brain.mjs /path/to/microfly-reference
.venv-policy/bin/python tools/compare_fly_replay.py /path/to/microduck/robot_walk.xml
```

첫 명령은 로컬 포트 5220을 사용합니다. 두 번째 명령은 원본 XML 옆의 메시 파일도 필요합니다. 공개 Pages에서 이 뇌 실험이 실행되는 것은 아니며 현재는 로컬 실험입니다. 다음 합격 조건은 여러 시드에서 전진·회전 추종을 통과한 뒤 목표 접근과 입력 차단을 검증하는 것입니다.

실제 보드 후보와 CPU 실측, 모터 전압 차이는 [온보드 실행 설계](ONBOARD_COMPUTE.md)에 정리했습니다.

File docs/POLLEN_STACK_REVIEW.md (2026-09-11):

# Pollen Robotics 조사와 Micro X 적용 판단

조사일: 2026-09-11. **MuJoCo는 전체 제품의 한 구성요소입니다.** X는 보행 학습, 실행 제어, 인식·표현, 제품 운영을 구분해 검증합니다. 아래의 공식 설명과 X에서 직접 확인한 결과를 혼동하지 않습니다.

| 계층 | 공식 구성·자료 | X의 현재 상태와 판단 |
|---|---|---|
| 학습 | mjlab / MuJoCo Warp, PPO, BAM XL330, 지연·전압·마찰·관측 오차 랜덤화, 별도 backlash 변형 | 공식 고정 버전에서 GPU 실행 확인. 같은 recipe에 X 모델을 연결했으며 장기 학습 평가 진행. 간단한 CPU PPO는 보조 실습으로 유지 |
| 정책 실행 | 정규화가 포함된 ONNX, 61개 관측·14개 행동, 50Hz, 보행·기립·기술 전환 | 보행·기립 연결 확인. 모든 기술·전환·복구 호환을 검증한 것은 아님 |
| 웹 실험 | 브라우저 WASM 물리 + ONNX 추론 | 공식 웹 직접 조작 확인. X는 별도 로컬 MuJoCo/BAM 서버에 실제 조작 화면을 연결; 공개 Pages는 정지 미리 보기 |
| 로봇 운영 | robotd 중심 제어, 별도 미디어·센서·설정·업데이트 서비스 | X의 로컬 실험 서버는 이 전체 운영 시스템을 대체하지 않음. 실물 버스·보호·복구·업데이트는 추가 구현/시험 대상 |
| 통합 시뮬레이션 | 실제 daemon + 가상 모터·센서, 컨테이너·통신 장애 시험 | 공식 문서를 확인했으며 X에서 이 경로를 실행한 것으로 표시하지 않음 |
| 시각 | 단안 영상의 물체 검출, ONNX 및 RKNN 변환 | 카메라 하나 유지. X 인식 성능·전력·열 예산과 데이터 수집 필요 |
| 표현·음성 | 감정 동작 키프레임 + 소리, Reachy Mini의 GStreamer / WebRTC 미디어 구조 | 동작·표현과 보행의 연동을 참고. 브라우저 TTS를 실물 음성 시스템 완성으로 보지 않음 |

학습/실행 구성의 근거는 [공식 RL 저장소](https://github.com/pollen-robotics/microduck_rl), [정책 저장소](https://huggingface.co/pollen-robotics/microduck-policies)입니다. 현재 X 실행은 RL commit `2b25a48b08f1f17bc38c90bb03144c81fbd9ed07`에 고정했습니다. 기본 학습과 backlash 변형은 별도이므로 현재 X 시험에 기어 유격 모델까지 적용됐다고 주장하지 않습니다.

[공식 운영 설계](https://github.com/pollen-robotics/microduck/blob/6507d2e960417aaa4ecd38eccf59b2dcf586ecd2/docs/design/architecture.md)는 일부 설계 목표를 포함합니다. [통합 시뮬레이션 문서](https://github.com/pollen-robotics/microduck/blob/6507d2e960417aaa4ecd38eccf59b2dcf586ecd2/docs/design/simulation.md)는 실제 제어 프로그램을 가상 장치와 연결하는 구현을 설명합니다. 물리 엔진만 통과하면 제어 제품도 통과한다고 추론할 수 없습니다.

[공식 감정 데이터](https://huggingface.co/datasets/pollen-robotics/microduck-emotions)는 머리·몸통·소리·정책 전환을 함께 다룹니다. 머리 이동이 실물 보행에 영향을 주었다는 경험도 기록돼 있으므로, X 외형 질량을 바꾸고 감정 동작만 복사하는 접근은 피합니다. [Reachy Mini 미디어 설명](https://huggingface.co/blog/pollen-robotics/reachy-mini-media-stack)은 영상·양방향 음성·로컬/원격 SDK 구조의 참고입니다. Reachy Mini 기능을 Microduck이나 X의 기능으로 간주하지 않습니다.

## 상업용 적용 판단

원본 하드웨어와 소프트웨어·정책의 권리는 별개입니다. 원본 3D 하드웨어는 상업용 X 파일에 포함하지 않으며, 기능 치수 측정은 별도로 출처를 표시합니다. 이는 법적 권리 전체에 대한 승인 판정이 아닙니다.

[Microduck 검출기 카드](https://huggingface.co/pollen-robotics/microduck-duck-detector)는 Apache-2.0을 표시하지만 YOLO11n 기반이라고도 명시합니다. [Ultralytics 공식 안내](https://www.ultralytics.com/license)는 자사 모델·코드에 별도 AGPL/Enterprise 조건을 설명합니다. 상위 모델과 학습 경로의 권리가 해소됐다는 증거 없이 카드의 태그 하나만으로 상업용 X에 포함하지 않습니다. 이 검출기는 현재 조사 대상이며 X에 통합하거나 배포하지 않았습니다.

## 다음 합격 기준

1. 새로운 초기 조건에서 정지·전진·회전의 속도 오차와 넘어짐을 함께 평가.
2. 장기 학습 정책을 공식 실행용 정규화 포함 ONNX로 내보내 동일 시험 재실행.
3. 제품 제어 루프·정책 전환·센서 중단·복구를 통합 환경에서 검증.
4. 단일 카메라의 인식·지연·전력과 기구 시야, 목 질량·배선 검증.
5. 팔·돌출 발톱 없는 독자 기구를 실제 부품과 조립해 내구성 확인.

현재 기록: [공식 기준 시험](OFFICIAL_BASELINE.md), [X 제어 호환 범위](COMPATIBILITY.md). 제품 우위나 양산 가능 여부는 이 조사만으로 입증되지 않습니다.

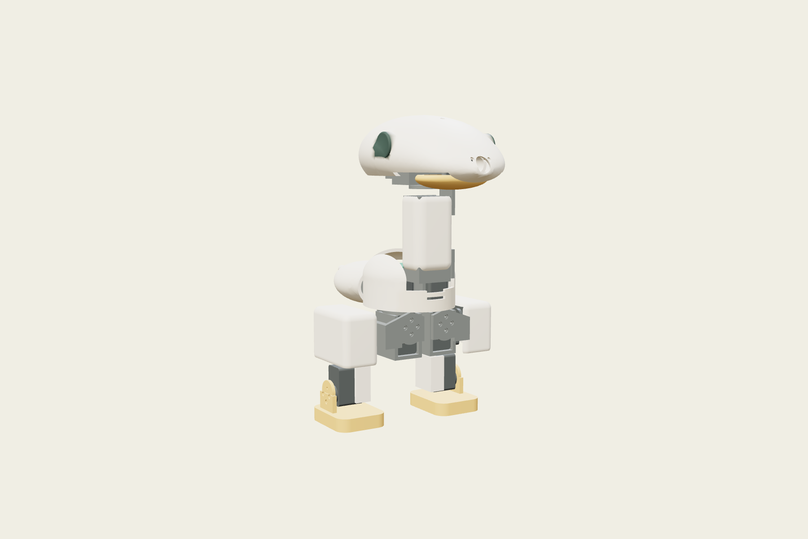
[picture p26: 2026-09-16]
artifacts/readme_face.png

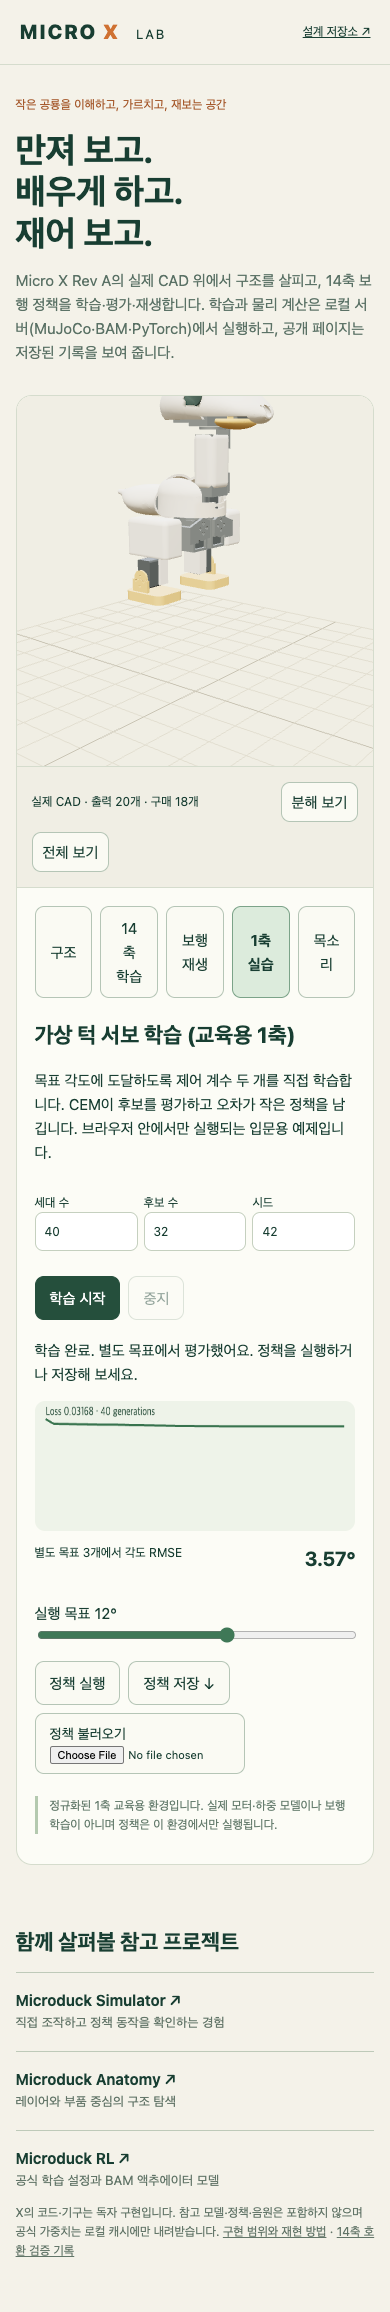
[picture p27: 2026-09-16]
artifacts/lab_mobile.png

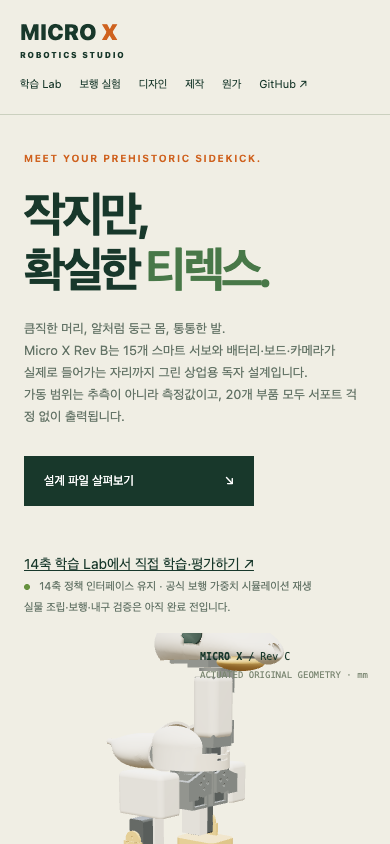
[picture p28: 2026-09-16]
artifacts/web_mobile.png

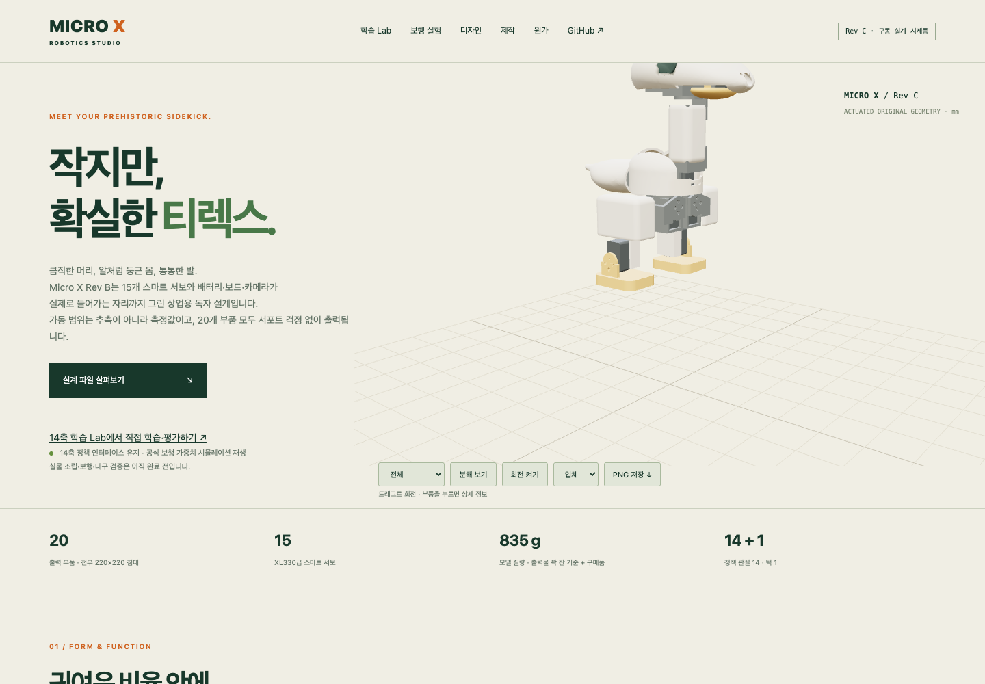
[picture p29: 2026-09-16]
artifacts/web_desktop.png

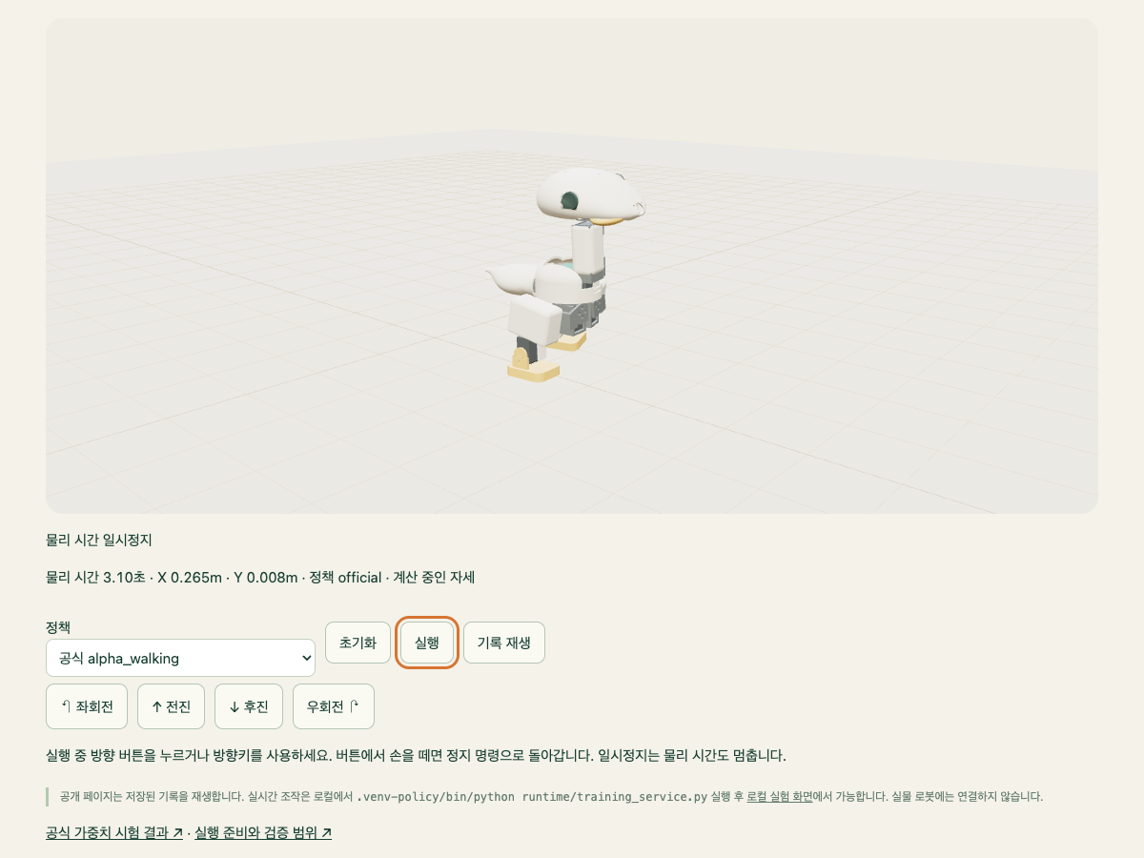
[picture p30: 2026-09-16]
artifacts/simulator_desktop.png

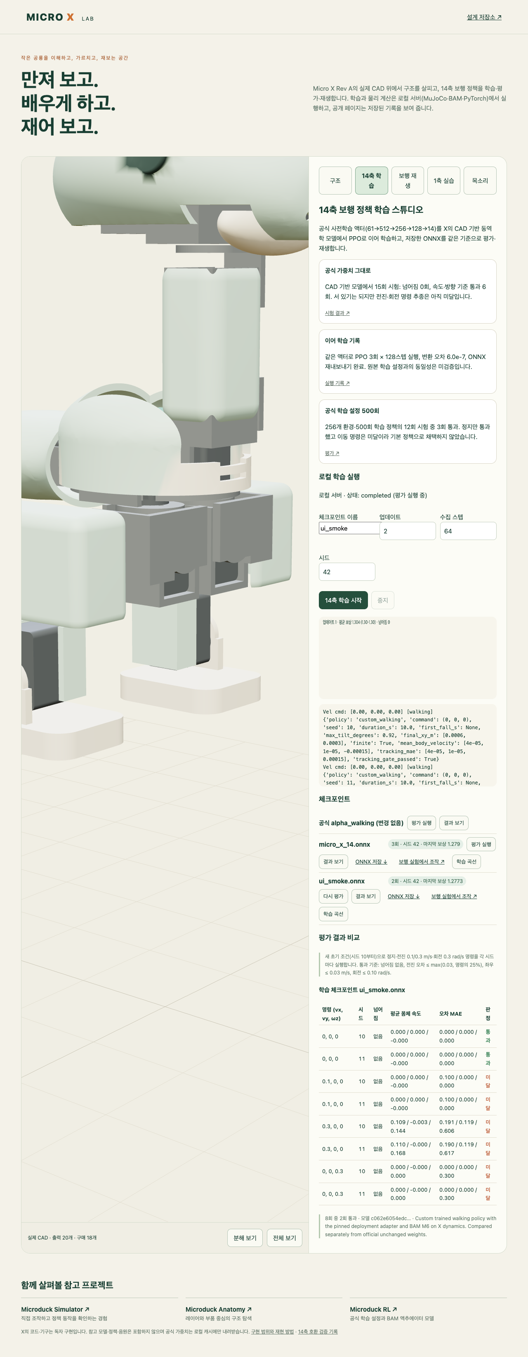
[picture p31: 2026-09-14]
artifacts/compat_workbench.png

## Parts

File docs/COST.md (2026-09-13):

# 원가 가정 (견적이 아님)

기준 시점 2026-09-13. 웹의 계산기는 아래 입력을 기본값으로 쓰며 모두 편집 가능합니다. 세금·배송·관세·금형·개발비·인증·포장·유통·보증·마진은 제외합니다.

| 항목 | 기본값 | 근거 |
|---|---|---|
| 모터 15개 | $27.49 × 15 = $412.35 | XL330-M288-T ROBOTIS 미국 소매가 1개, 수량 할인 미표시 (https://www.robotis.us/dynamixel-xl330-m288-t/) |
| 전장·배터리·카메라·체결 | $110 (가정) | 싱글보드 컴퓨터(50 × 27 mm까지), IMU, 마이크·스피커, TTL 버스 어댑터, 전원 보드, 2S 18650급 배터리, Camera Module 3급, 나사류 |
| 출력·마감·조립 | $45 (가정) | 20개 출력 부품 347 g(꽉 찬 기준; 실제 인필은 더 적음), 조립 인건 |
| 수율 | 95 % (가정) | |
| **계산기 합계** | **≈ $597** | 소매가 모터 기준이므로 Microduck 사전예약가 $399보다 높음 |

결론은 명확합니다: **소매가 XL330 15개만으로 Microduck 판매가를 넘습니다.** 상업화 경로는 (1) 모터 대량 견적, (2) 헤드·턱 등 저부하 축에 저가 서보 혼용 검토(정책 호환은 다리 10축과 목 4축에 한정되므로 턱은 자유), (3) 출력 대신 사출은 수량이 확정된 뒤. 이 저장소는 계산기와 가정을 공개하고 실제 견적을 받은 뒤 값을 바꿉니다.

## Microduck 참고 가격 (공개 정보)

- 조립 완제품 $399 (사전예약, 세금·배송 별도), 게임패드 포함, 배터리 1개 (NP-F550, 2600 mAh, 약 1시간). 출처: Pollen Robotics 프레스킷·스토어, Engadget 2026-08-27.
- 액세서리 팩 $39, 충전 팩 $39, 개발 팩 $119.
- 하드웨어 설계 파일은 비공개(소프트웨어만 오픈소스). Micro X는 독자 설계로 이 제약을 받지 않습니다.

## 설계로 낮추는 항목

- 공용 M2/M3 두 규격, 혼·아이들러 판 8볼트로 서보 교체 표준화.
- 배터리는 2S 18650급 팩으로, 셀과 충전기를 어디서나 구할 수 있고 꼬리 커버만 빼면 교체됩니다.
- 외장 7개(몸통·목 커버·두개골·아래턱·꼬리·발 2)와 프레임 13개로 분리해 외장만 사출 전환 가능.
- 발 바닥은 평평하고 속이 비어 TPU 패드만 교체.
- 모든 부품이 220 × 220 침대에 들어가고 브래킷은 서포트가 필요 없어 출력 시간과 후처리가 줄어듭니다(`artifacts/printability.json`).

실측(슬라이서 질량, 출력 시간, 조립 분, 1차 수율)은 실물 제작 후 이 파일에 추가합니다.

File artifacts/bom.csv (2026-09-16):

item | quantity | kind | link | basis | mass_g | status | file
left_yaw2roll | 1 | printed | left_yaw2roll | PLA solid-equivalent volume; infill and material not frozen | 17.03 | Rev C digital design | models/step/left_yaw2roll.step
left_hip | 1 | printed | left_hip | PLA solid-equivalent volume; infill and material not frozen | 6.28 | Rev C digital design | models/step/left_hip.step
left_upper_leg | 1 | printed | left_upper_leg | PLA solid-equivalent volume; infill and material not frozen | 23.06 | Rev C digital design | models/step/left_upper_leg.step
left_lower_leg | 1 | printed | left_lower_leg | PLA solid-equivalent volume; infill and material not frozen | 8.55 | Rev C digital design | models/step/left_lower_leg.step
left_foot | 1 | printed | left_foot | PLA solid-equivalent volume; infill and material not frozen | 24.94 | Rev C digital design | models/step/left_foot.step
right_yaw2roll | 1 | printed | right_yaw2roll | PLA solid-equivalent volume; infill and material not frozen | 17.03 | Rev C digital design | models/step/right_yaw2roll.step
right_hip | 1 | printed | right_hip | PLA solid-equivalent volume; infill and material not frozen | 6.28 | Rev C digital design | models/step/right_hip.step
right_upper_leg | 1 | printed | right_upper_leg | PLA solid-equivalent volume; infill and material not frozen | 23.06 | Rev C digital design | models/step/right_upper_leg.step
right_lower_leg | 1 | printed | right_lower_leg | PLA solid-equivalent volume; infill and material not frozen | 8.55 | Rev C digital design | models/step/right_lower_leg.step
right_foot | 1 | printed | right_foot | PLA solid-equivalent volume; infill and material not frozen | 24.94 | Rev C digital design | models/step/right_foot.step
chassis | 1 | printed | trunk | PLA solid-equivalent volume; infill and material not frozen | 44.48 | Rev C digital design | models/step/chassis.step
torso_shell | 1 | printed | trunk | PLA solid-equivalent volume; infill and material not frozen | 29.07 | Rev C digital design | models/step/torso_shell.step
tail_cover | 1 | printed | trunk | PLA solid-equivalent volume; infill and material not frozen | 39.08 | Rev C digital design | models/step/tail_cover.step
neck_link | 1 | printed | neck | PLA solid-equivalent volume; infill and material not frozen | 16.0 | Rev C digital design | models/step/neck_link.step
neck_sleeve | 1 | printed | neck | PLA solid-equivalent volume; infill and material not frozen | 13.37 | Rev C digital design | models/step/neck_sleeve.step
head_base | 1 | printed | head_base | PLA solid-equivalent volume; infill and material not frozen | 4.37 | Rev C digital design | models/step/head_base.step
head_yoke | 1 | printed | head_yoke | PLA solid-equivalent volume; infill and material not frozen | 15.41 | Rev C digital design | models/step/head_yoke.step
head_frame | 1 | printed | head | PLA solid-equivalent volume; infill and material not frozen | 25.61 | Rev C digital design | models/step/head_frame.step
skull | 1 | printed | head | PLA solid-equivalent volume; infill and material not frozen | 77.95 | Rev C digital design | models/step/skull.step
jaw_beak | 1 | printed | jaw | PLA solid-equivalent volume; infill and material not frozen | 11.1 | Rev C digital design | models/step/jaw_beak.step
servo_left_hip_yaw | 1 | actuator | trunk | XL330-class smart servo envelope; confirm the case hole pattern before ordering | 18.0 | purchased envelope; supplier quote pending | models/purchased/servo_left_hip_yaw.stl
servo_left_hip_roll | 1 | actuator | left_yaw2roll | XL330-class smart servo envelope; confirm the case hole pattern before ordering | 18.0 | purchased envelope; supplier quote pending | models/purchased/servo_left_hip_roll.stl
servo_left_hip_pitch | 1 | actuator | left_upper_leg | XL330-class smart servo envelope; confirm the case hole pattern before ordering | 18.0 | purchased envelope; supplier quote pending | models/purchased/servo_left_hip_pitch.stl
servo_left_knee | 1 | actuator | left_upper_leg | XL330-class smart servo envelope; confirm the case hole pattern before ordering | 18.0 | purchased envelope; supplier quote pending | models/purchased/servo_left_knee.stl
servo_left_ankle | 1 | actuator | left_lower_leg | XL330-class smart servo envelope; confirm the case hole pattern before ordering | 18.0 | purchased envelope; supplier quote pending | models/purchased/servo_left_ankle.stl
servo_right_hip_yaw | 1 | actuator | trunk | XL330-class smart servo envelope; confirm the case hole pattern before ordering | 18.0 | purchased envelope; supplier quote pending | models/purchased/servo_right_hip_yaw.stl
servo_right_hip_roll | 1 | actuator | right_yaw2roll | XL330-class smart servo envelope; confirm the case hole pattern before ordering | 18.0 | purchased envelope; supplier quote pending | models/purchased/servo_right_hip_roll.stl
servo_right_hip_pitch | 1 | actuator | right_upper_leg | XL330-class smart servo envelope; confirm the case hole pattern before ordering | 18.0 | purchased envelope; supplier quote pending | models/purchased/servo_right_hip_pitch.stl
servo_right_knee | 1 | actuator | right_upper_leg | XL330-class smart servo envelope; confirm the case hole pattern before ordering | 18.0 | purchased envelope; supplier quote pending | models/purchased/servo_right_knee.stl
servo_right_ankle | 1 | actuator | right_lower_leg | XL330-class smart servo envelope; confirm the case hole pattern before ordering | 18.0 | purchased envelope; supplier quote pending | models/purchased/servo_right_ankle.stl
servo_neck_pitch | 1 | actuator | neck | XL330-class smart servo envelope; confirm the case hole pattern before ordering | 18.0 | purchased envelope; supplier quote pending | models/purchased/servo_neck_pitch.stl
servo_head_pitch | 1 | actuator | neck | XL330-class smart servo envelope; confirm the case hole pattern before ordering | 18.0 | purchased envelope; supplier quote pending | models/purchased/servo_head_pitch.stl
servo_head_yaw | 1 | actuator | head_yoke | XL330-class smart servo envelope; confirm the case hole pattern before ordering | 18.0 | purchased envelope; supplier quote pending | models/purchased/servo_head_yaw.stl
servo_head_roll | 1 | actuator | head | XL330-class smart servo envelope; confirm the case hole pattern before ordering | 18.0 | purchased envelope; supplier quote pending | models/purchased/servo_head_roll.stl
servo_jaw | 1 | actuator | head | XL330-class smart servo envelope; confirm the case hole pattern before ordering | 18.0 | purchased envelope; supplier quote pending | models/purchased/servo_jaw.stl
battery_pack | 1 | battery | trunk | Removable 2S 18650 pack, 65 x 37 x 19 mm class, 7.4 V ~3000 mAh; slides out with the tail cover | 95 | purchased envelope; supplier quote pending | models/purchased/battery_pack.stl
compute_board | 1 | electronics | trunk | Single-board computer up to 50 x 27 mm on the trunk deck above the hip servos; a larger module needs the reserved head bay | 30 | purchased envelope; supplier quote pending | models/purchased/compute_board.stl
camera_module_3 | 1 | camera | head | Raspberry Pi Camera Module 3 Standard class, 25 x 24 mm board | 4 | purchased envelope; supplier quote pending | models/purchased/camera_module_3.stl
# measured joint travel (deg) | min | max
left_hip_yaw | -28.6 | 29.8
left_hip_roll | -22.9 | 20.1
left_hip_pitch | -90.0 | 51.6
left_knee | -90.0 | 63.0
left_ankle | -31.5 | 31.5
right_hip_yaw | -29.8 | 28.6
right_hip_roll | -20.1 | 22.9
right_hip_pitch | -51.6 | 90.0
right_knee | -63.0 | 90.0
right_ankle | -31.5 | 31.5
neck_pitch | -11.5 | 37.2
head_pitch | -34.4 | 34.4
head_yaw | -114.6 | 43.0
head_roll | -5.7 | 8.6
jaw | 0.0 | 5.7
M2 x 6 screws, servo horn/idler to clevis plates | 120 | hardware |  | Four per horn and four per idler pattern; confirm thread engagement in the printed plate |  | Not procurement-ready
M2 case screws or keeper clips, servo body retention | 30 | hardware |  | Depends on the confirmed XL330 case hole pattern |  | Not procurement-ready
M3 x 8 plastic thread-forming screws (shell to chassis, skull to rail, eyes, tail cover) | 12 | hardware |  | Pilot Ø2.6 in printed bosses; coupon test first |  | Not procurement-ready
16 x 22 x 4 mm bearing (optional hip yaw support) | 2 | hardware |  | Optional plain/rolling bearing under each hip yaw plate |  | Design option
2S 18650 battery pack, 65 x 37 x 19 mm class | 1 | hardware |  | Slides out with the tail cover; cells and chargers are commodity items |  | Not procurement-ready
IMU board, microphone, speaker, wiring, TTL bus adapter, power board | 1 | hardware |  | Not yet placed in CAD; trunk deck volume reserved |  | Architecture decision required
TPU sole pads | 2 | hardware |  | Fill the hollow sole underside; durometer to be chosen |  | Follow-up

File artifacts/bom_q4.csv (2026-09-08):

part | quantity | material_basis | mass_g | status | file
torso_lower | 1 | PLA volume estimate; material not frozen | 61.65 | P0 prototype | models/q4/step/torso_lower.step
torso_upper | 1 | PLA volume estimate; material not frozen | 33.02 | P0 prototype | models/q4/step/torso_upper.step
neck_cradle | 1 | PLA volume estimate; material not frozen | 10.53 | P0 prototype | models/q4/step/neck_cradle.step
eye_left | 1 | PLA volume estimate; material not frozen | 4.19 | P0 prototype | models/q4/step/eye_left.step
eye_right | 1 | PLA volume estimate; material not frozen | 4.19 | P0 prototype | models/q4/step/eye_right.step
camera_carrier | 1 | PLA volume estimate; material not frozen | 1.58 | P0 prototype | models/q4/step/camera_carrier.step
skull | 1 | PLA volume estimate; material not frozen | 52.97 | P0 prototype | models/q4/step/skull.step
jaw | 1 | PLA volume estimate; material not frozen | 39.47 | P0 prototype | models/q4/step/jaw.step
tail_left | 1 | PLA volume estimate; material not frozen | 13.31 | P0 prototype | models/q4/step/tail_left.step
tail_right | 1 | PLA volume estimate; material not frozen | 13.31 | P0 prototype | models/q4/step/tail_right.step
front_hindleg_left | 1 | PLA volume estimate; material not frozen | 49.57 | P0 prototype | models/q4/step/front_hindleg_left.step
front_foot_left | 1 | PLA volume estimate; material not frozen | 32.62 | P0 prototype | models/q4/step/front_foot_left.step
front_hindleg_right | 1 | PLA volume estimate; material not frozen | 49.57 | P0 prototype | models/q4/step/front_hindleg_right.step
front_foot_right | 1 | PLA volume estimate; material not frozen | 32.62 | P0 prototype | models/q4/step/front_foot_right.step
rear_hindleg_left | 1 | PLA volume estimate; material not frozen | 49.57 | P0 prototype | models/q4/step/rear_hindleg_left.step
rear_foot_left | 1 | PLA volume estimate; material not frozen | 32.62 | P0 prototype | models/q4/step/rear_foot_left.step
rear_hindleg_right | 1 | PLA volume estimate; material not frozen | 49.57 | P0 prototype | models/q4/step/rear_hindleg_right.step
rear_foot_right | 1 | PLA volume estimate; material not frozen | 32.62 | P0 prototype | models/q4/step/rear_foot_right.step
side_rail_left | 1 | PLA volume estimate; material not frozen | 10.29 | P0 prototype | models/q4/step/side_rail_left.step
side_rail_right | 1 | PLA volume estimate; material not frozen | 10.29 | P0 prototype | models/q4/step/side_rail_right.step
Eye M3 plastic thread-forming screw | 2 | Candidate length 8 mm; verify chosen supplier and installed torque |  | Prototype fit/pull test required | docs/DESIGN_QUALITY.md
Eye M3 washer | 2 | Candidate 1 mm thickness; verify bearing area and actual screw head |  | Prototype fit required | docs/DESIGN_QUALITY.md
Camera carrier M2 screws/nuts/washers | 4 | Candidate M2 x 10; PCB and nut clearance fit pending |  | Not procurement-ready | docs/FUNCTIONS.md
Camera carrier M3 plastic thread-forming screws | 2 | Candidate M3 x 10; engagement and torque test pending |  | Not procurement-ready | docs/FUNCTIONS.md
M3 screws and nuts | TBD | Purchased; length/retention audit pending |  | Not procurement-ready | docs/ASSEMBLY.md
Actuators/electronics | TBD | Not integrated |  | Architecture decision required | docs/COST.md

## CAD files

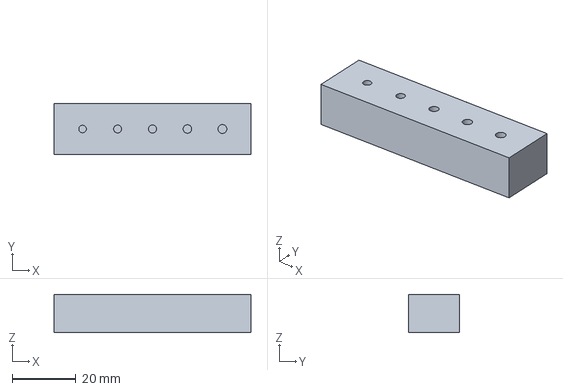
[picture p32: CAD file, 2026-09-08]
models/coupons/m3_pilot_coupon.step
62.0 x 16.0 x 12.0 mm

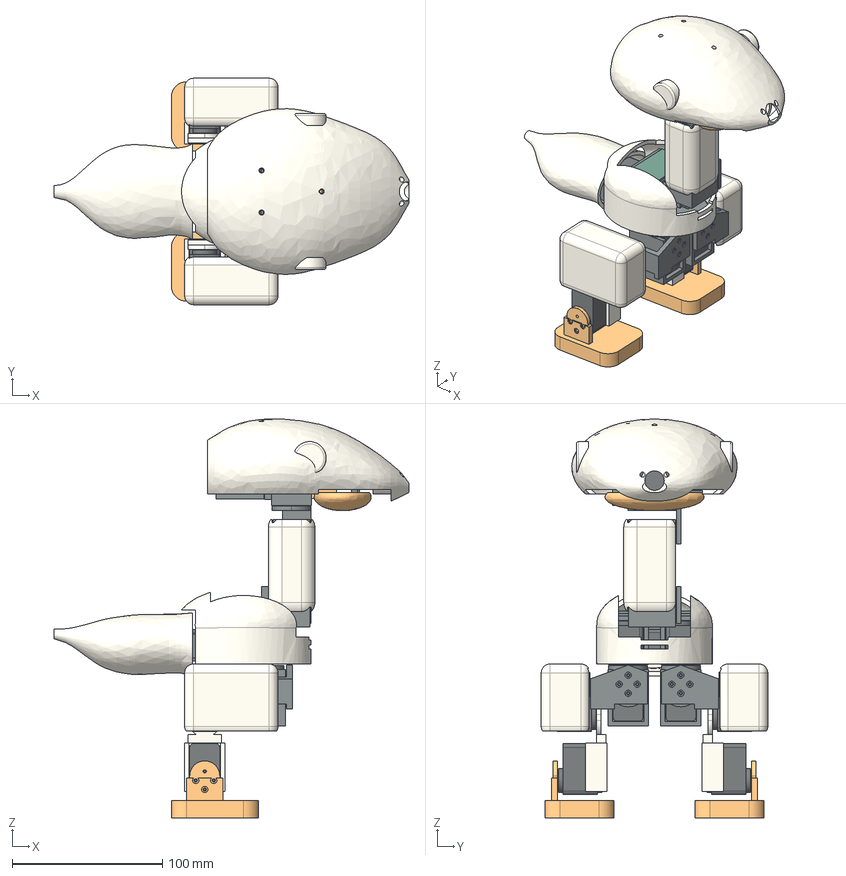
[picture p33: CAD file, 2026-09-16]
models/micro_x.step
236.0 x 150.8 x 265.5 mm
left_yaw2roll
left_hip
left_upper_leg
left_lower_leg
left_foot
right_yaw2roll
right_hip
right_upper_leg
right_lower_leg
right_foot
chassis
torso_shell
tail_cover
neck_link
neck_sleeve
head_base
head_yoke
head_frame
skull
jaw_beak
servo_left_hip_yaw
servo_left_hip_roll
servo_left_hip_pitch
servo_left_knee
servo_left_ankle
servo_right_hip_yaw
servo_right_hip_roll
servo_right_hip_pitch
servo_right_knee
servo_right_ankle
servo_neck_pitch
servo_head_pitch
servo_head_yaw
servo_head_roll
servo_jaw
battery_pack
compute_board
camera_module_3

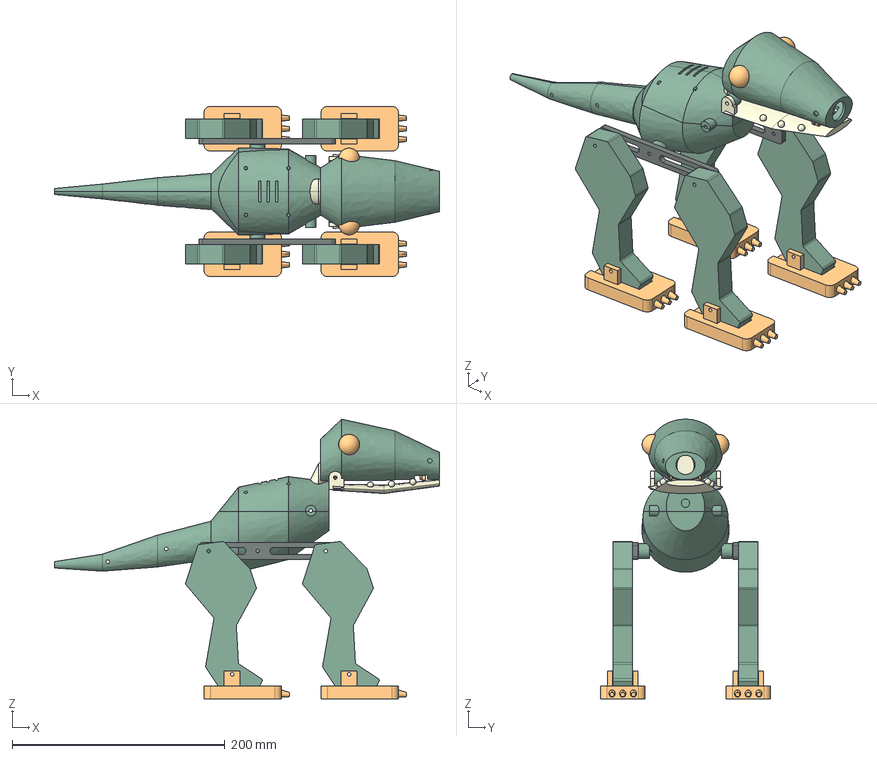
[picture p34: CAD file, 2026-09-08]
models/q4/micro_x_q4.step
362.0 x 160.0 x 263.0 mm
torso_lower
torso_upper
neck_cradle
eye_left
eye_right
camera_carrier
skull
jaw
tail_left
tail_right
front_hindleg_left
front_foot_left
front_hindleg_right
front_foot_right
rear_hindleg_left
rear_foot_left
rear_hindleg_right
rear_foot_right
side_rail_left
side_rail_right

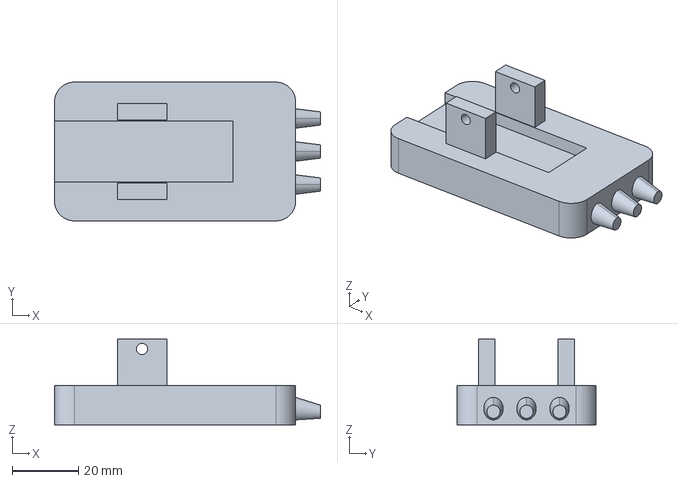
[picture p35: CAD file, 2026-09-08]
models/q4/step/front_foot_right.step
80.5 x 42.0 x 26.0 mm

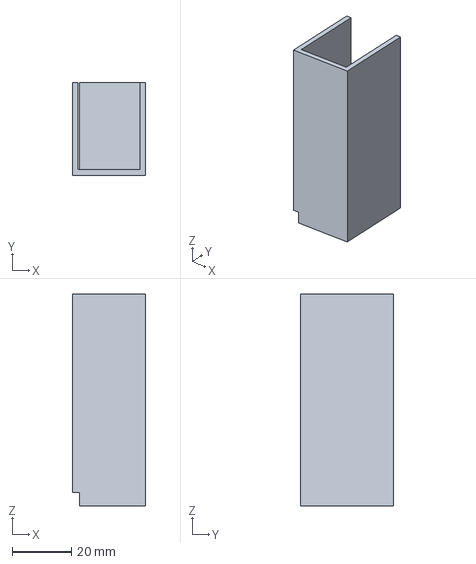
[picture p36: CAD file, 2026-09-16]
models/step/neck_link.step
24.8 x 31.4 x 71.7 mm

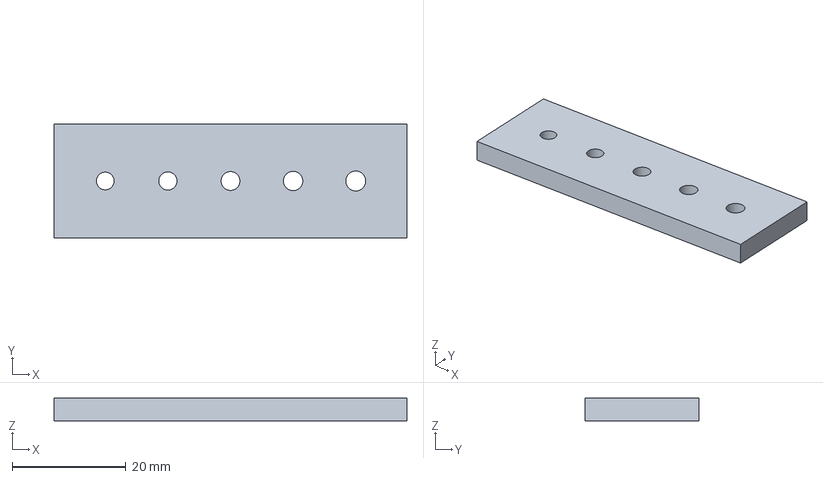
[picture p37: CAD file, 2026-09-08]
models/coupons/m3_clearance_coupon.step
62.0 x 20.0 x 4.00 mm

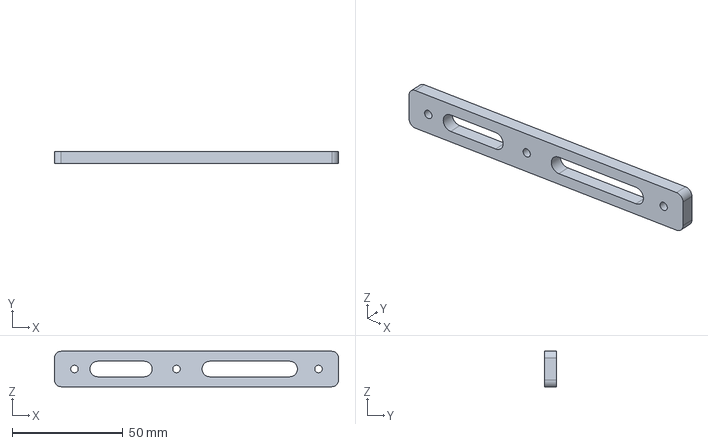
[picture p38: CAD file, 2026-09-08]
models/q4/step/side_rail_right.step
128.0 x 5.40 x 16.0 mm

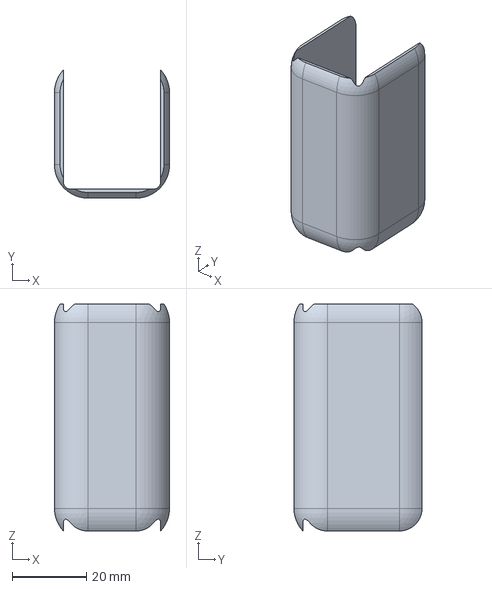
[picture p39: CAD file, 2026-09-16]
models/step/neck_sleeve.step
31.0 x 34.5 x 61.1 mm

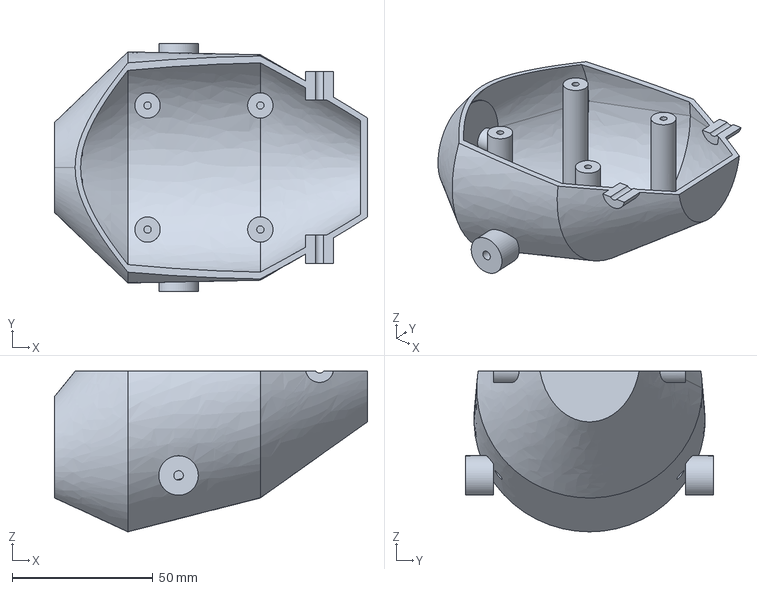
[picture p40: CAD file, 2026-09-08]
models/q4/step/torso_lower.step
111.0 x 88.0 x 57.0 mm

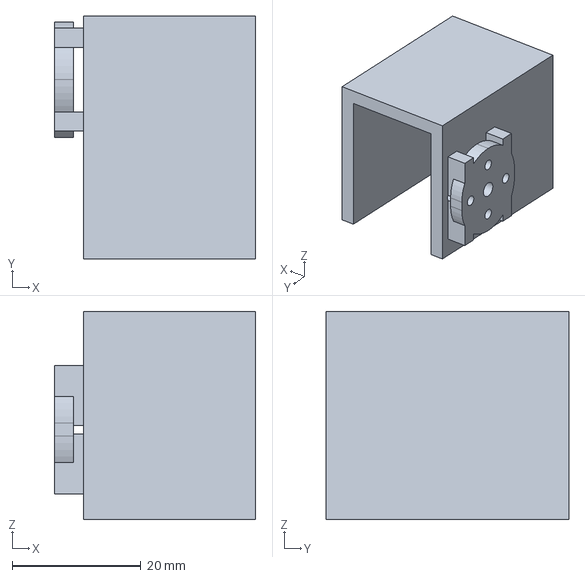
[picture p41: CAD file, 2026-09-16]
models/step/head_yoke.step
31.3 x 37.8 x 32.4 mm

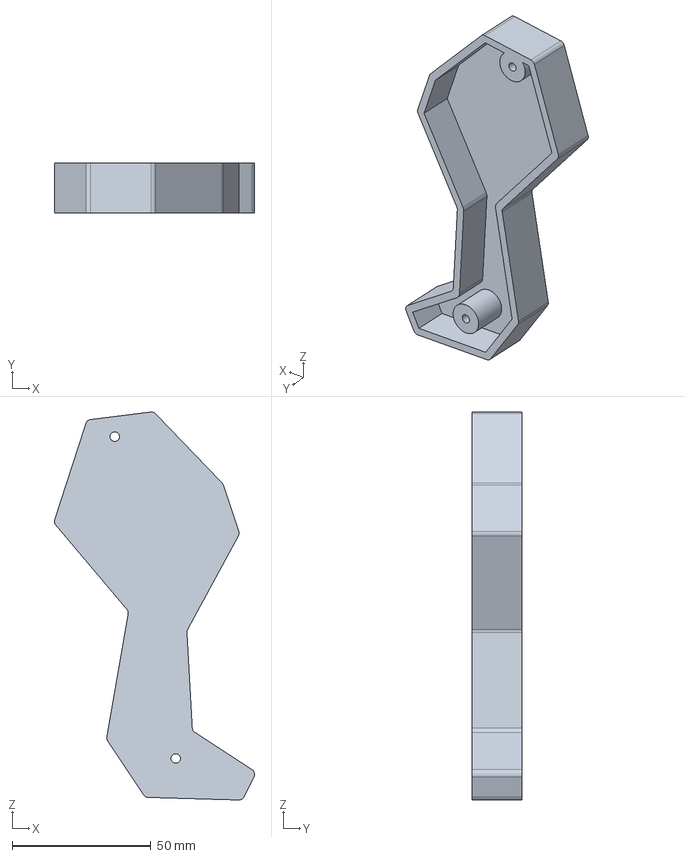
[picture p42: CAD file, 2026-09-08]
models/q4/step/front_hindleg_right.step
72.2 x 18.0 x 139.9 mm

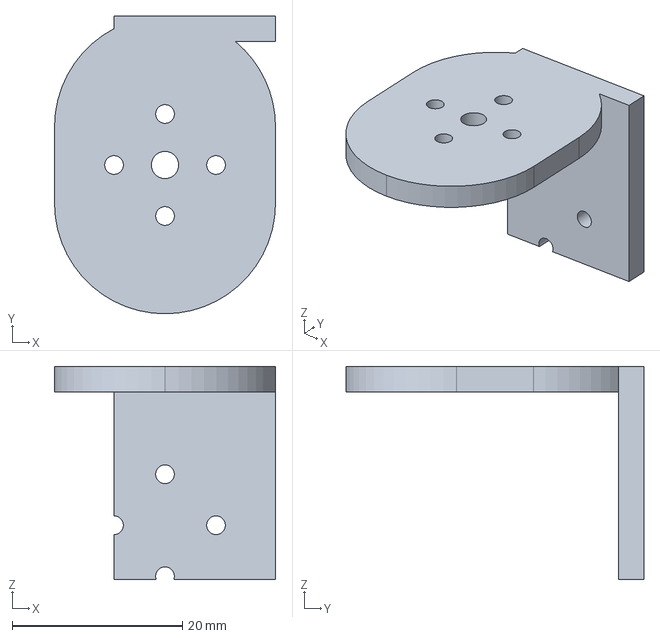
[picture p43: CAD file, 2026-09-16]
models/step/head_base.step
26.0 x 35.0 x 25.1 mm

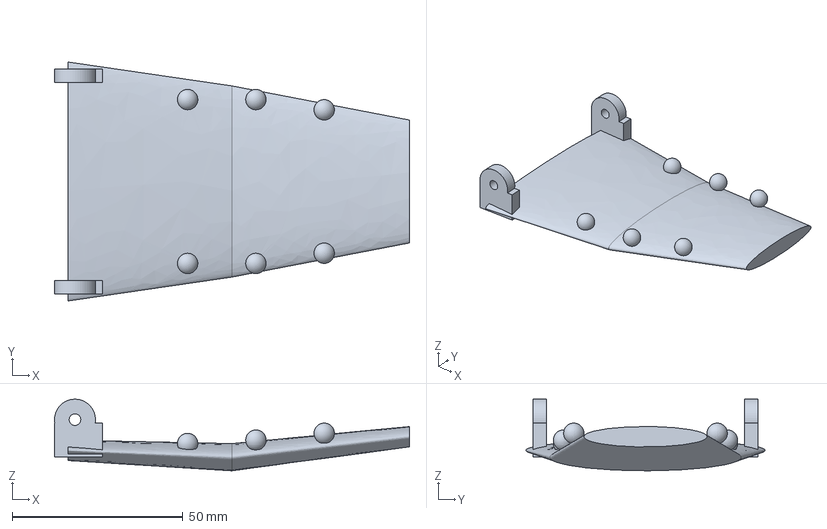
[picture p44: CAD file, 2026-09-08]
models/q4/step/jaw.step
104.0 x 70.0 x 21.0 mm

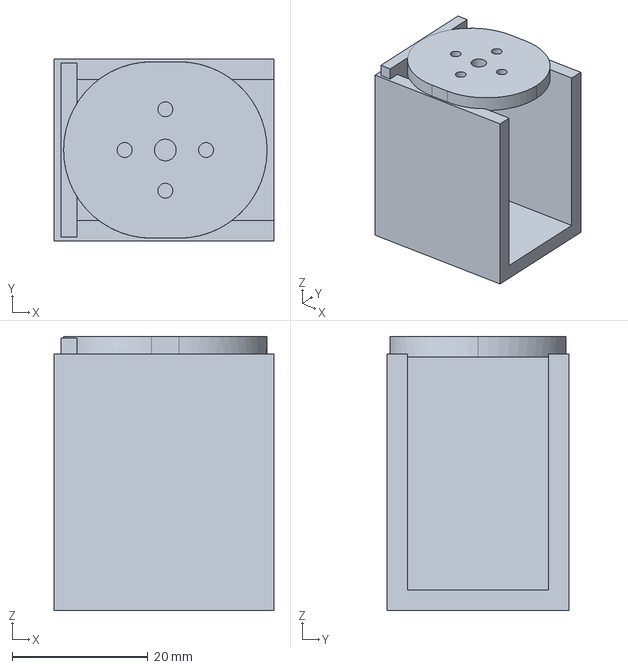
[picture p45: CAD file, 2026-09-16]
models/step/right_yaw2roll.step
32.4 x 26.8 x 40.4 mm

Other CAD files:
models/q4/step/front_foot_left.step
models/step/torso_shell.step
models/q4/step/front_hindleg_left.step
models/step/right_upper_leg.step
models/chassis.stl
models/coupons/m3_clearance_coupon.stl
models/coupons/m3_pilot_coupon.stl
models/eye_left.stl
models/eye_right.stl
models/head_base.stl
models/head_frame.stl
models/head_yoke.stl
models/jaw_beak.stl
models/left_foot.stl
models/left_hip.stl
models/left_lower_leg.stl
models/left_shin.stl
models/left_thigh.stl
models/left_upper_leg.stl
models/left_yaw2roll.stl
models/neck_link.stl
models/neck_sleeve.stl
models/print/chassis.stl
models/print/eye_left.stl
models/print/eye_right.stl
models/print/head_base.stl
models/print/head_frame.stl
models/print/head_yoke.stl
models/print/jaw_beak.stl
models/print/left_foot.stl
models/print/left_hip.stl
models/print/left_lower_leg.stl
models/print/left_shin.stl
models/print/left_thigh.stl
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

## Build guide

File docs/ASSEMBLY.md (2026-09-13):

# Rev B 조립 순서와 인터페이스

디지털 설계의 조립 의도입니다. 실물 출력 공차·나사 체결·케이블 경로는 아직 확인 전입니다. 좌표는 조립 기준 프레임(mm, X 앞, Y 왼쪽, Z 위, 바닥 Z=0, 몸통 기준 프레임 Z=120). `models/print/`는 출력 방향으로 눕힌 STL, `models/step/`와 `models/*.stl`은 조립 좌표입니다. 모든 부품은 다리를 곧게 편 **설계 자세**로 그려져 있습니다.

## 공통 규칙

- **서보 고정**: 서보 몸체는 한쪽 링크의 U자 채널에 0.4 mm 여유로 들어가고, 이웃 링크의 혼 판이 출력 혼에 M2 4개로 붙습니다. 판 두께 3 mm, 혼 면과 판 사이 0.5 mm, 볼트는 Ø12 원 위 4×Ø2.2입니다. 서보 몸체 자체는 채널 벽과 이웃 판이 잡습니다. 케이스 측면 홀은 아직 모델에 없으므로, 실물 서보의 홀 패턴을 확인해 몸체 고정 나사나 키퍼를 추가해야 합니다(`engineering/actuator_interface.json`).
- **M3 체결**: Ø2.6 파일럿(플라스틱용 태핑 나사)과 Ø3.4 관통. `models/coupons/`의 시편으로 프린터 보정 후 출력하세요.
- **출력**: 부품마다 방향이 고정되어 있습니다(`artifacts/printability.json`). 브래킷류는 면 하나를 침대에 붙이면 벽이 전부 수직이라 서포트가 필요 없습니다. 아래턱과 꼬리 커버는 곡면이라 브림을 권합니다.

## 1. 다리 (좌우 대칭, 왼쪽 기준)

1. **요·롤 브래킷** `left_yaw2roll` — 고관절 요 혼 판(z 112…115) 아래에 고관절 롤 서보용 U자 채널(벽 y 4.7…7.1 / 27.9…30.3, 바닥 캡 z 75.2…78). 롤 서보를 아래에서 넣고, 요 서보 혼에 M2 4개로 붙입니다. 판 면을 침대에 놓고 출력.
2. **고관절 브래킷** `left_hip` — 롤 혼 판(x 22.5…25.5)과 피치 혼 판(y 39.5…42.5)을 리브 하나로 이은 코너. 얇은 판 두 장뿐이라 6.7 g입니다.
3. **허벅지** `left_upper_leg` — 고관절 피치 서보와 무릎 서보를 나란히 감싸는 쉘. 안쪽(−Y)과 아래가 열려 있어 서보를 옆에서 넣고, 무릎을 접을 때 종아리가 들어올 공간이 됩니다. 바깥 면을 침대에 놓으면 공동이 위로 열려 서포트가 없습니다.
4. **종아리** `left_lower_leg` — 무릎 혼 판(y 35.5…38.5)에서 내려와 발목 서보를 감싸는 채널. 발이 기울 수 있도록 z 31 아래는 비어 있습니다.
5. **발** `left_foot` — 발목 혼 판이 바닥판까지 이어지고, 바닥은 평평하며(윗면·아랫면 모두 평면, 옆면만 라운드) 속이 비어 TPU 패드를 넣을 수 있습니다.

## 2. 몸통

1. **섀시** `chassis` — 타원 바닥판(z 118…121)에 고관절 요 서보 박스 2개, 목 피치 혼 판(x 6…39, y 14.5…17.5, z 145.3…167.4), 전장 데크(z 147…149.5, 보드 최대 50 × 27 mm), 배터리 트레이(x −92…−25), 쉘 보스 4개. 요 서보는 바닥판 구멍으로 넣어 요·롤 브래킷의 혼 판이 잡습니다. 바닥을 침대에 놓고 출력하며, 서보 박스의 천장은 약 21 mm 브리지입니다.
2. **몸통 쉘** `torso_shell` — 아래는 곧은 타원 통(z 121…142), 위는 돔. 앞 가슴 그릴, 목 슬롯, 뒤 배터리 개구가 있고 아래는 열려 있습니다. 옆면 구멍 4개(x −26 / 20, z 132)로 바깥에서 M3를 섀시 보스에 체결합니다. 열린 쪽을 아래로 놓고 출력.
3. **꼬리 커버** `tail_cover` — 단면 5개 로프트. 배터리를 트레이에 넣고 뒤에서 밀어 M3 2개로 고정합니다. 배터리 교체는 커버만 빼면 됩니다.

## 3. 목과 머리

1. **목 튜브** `neck_link` — 세로로 쌓인 목 피치·머리 피치 서보를 감싸는 사각 튜브. 혼이 나오는 +Y 쪽이 열려 있습니다.
2. **목 커버** `neck_sleeve` — 튜브 위에 씌우는 둥근 쉘. 목과 함께 기울어지며 몸통 슬롯 안에서 움직입니다.
3. **머리 베이스** `head_base` — 머리 피치 혼 판과 머리 요 혼 판. 머리가 요 회전해도 이 부품만 고정입니다.
4. **요크** `head_yoke` — 머리 요 서보를 담는 상자 + 머리 롤 혼 판까지 잇는 리브 2개.
5. **머리 프레임** `head_frame` — 한 덩이 쉘. 요크 위를 지나는 데크(z 261…263.4), 뒤 벽, 머리 롤 서보 벽, 턱 서보 행어, 앞쪽 빔과 기둥, 카메라 벽(CM3급 홀 Y ±10.5 / Z 232.85·245.35), 두개골 보스 3개.
6. **두개골** `skull` — 단면 7개 로프트. 아래와 뒤가 열려 있고, 주둥이 끝에 렌즈 후드, 콧구멍 2개가 있습니다. M3 3개로 프레임 보스에 위에서 체결합니다. **눈은 부품이 아니라 도색입니다.**
7. **아래턱** `jaw_beak` — 턱 서보 혼에 붙는 팔 하나와 둥근 부리. 입 개구(x 46…68)를 덮으며 17°까지 열립니다.

## 검증 상태와 남은 확인

- 설계 자세 정적 간섭 0건, 측정 가동 범위 안 관절별 샘플 충돌 0건 (`artifacts/interference.json`). 가동 범위는 `tools/travel.py`가 측정한 값이며 `engineering/joint_travel.json`에 있습니다.
- 미검증: 출력 공차, 서보 케이스 고정, 케이블 경로(목·머리 4축과 다리 5축), IMU·마이크·스피커·전원 보드, 낙하·피로·발열, 실제 보행.
- 출력 순서 권장: 시편 → 발·종아리·허벅지 한 세트 → 고관절 브래킷 → 몸통 → 머리.

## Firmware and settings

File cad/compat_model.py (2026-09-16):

"""Micro X Rev B 14-axis MuJoCo model, generated from the Rev A/B CAD.

Bodies, pivots and axes follow cad/layout.py (design pose = qpos 0, so no joint `ref`
offsets are needed and the policy HOME angles are ordinary joint targets). Masses and
inertias come from the printed-part meshes at PLA solid density plus purchased envelopes
with catalogue masses. Names the pinned inference adapter needs are kept: body
trunk_base, freejoint trunk_base_freejoint, site imu, the 14 joint/actuator names.
"""
from pathlib import Path
import json,sys,xml.etree.ElementTree as E
import numpy as np,trimesh,mujoco
R=Path(__file__).resolve().parents[1];sys.path.insert(0,str(R/'cad'))
import layout as L
DENSITY=1240.0
# Joint limits are the measured collision-free travel of the printed parts (tools/travel.py),
# not a wish list: the model can only command what the mechanism can actually do.
TRAVEL=json.loads((R/'engineering/joint_travel.json').read_text())['joints']
def vector(v):return ' '.join(f'{x:.9g}' for x in np.asarray(v,float))
def add(p,tag,**kw):return E.SubElement(p,tag,{k:str(v) for k,v in kw.items()})
def inertia_of(meshes):
    total=sum(m for m,_ in meshes);com=sum(m*me.center_mass for m,me in meshes)/total;I=np.zeros((3,3))
    for m,me in meshes:
        props=me.mass_properties;ratio=m/props['mass'] if props['mass']>0 else 0;d=me.center_mass-com
        I+=props['inertia']*ratio+m*(np.eye(3)*np.dot(d,d)-np.outer(d,d))
    return total,com,I
def build():
    report=json.loads((R/'artifacts/parts.json').read_text())
    pivots={b:(L.JOINT_OF_BODY[b]['P'] if b in L.JOINT_OF_BODY else L.TRUNK_ORIGIN) for b in L.BODIES}
    per_body={b:[] for b in L.BODIES};extents={};soles={}
    for p in report['parts']+report['purchased']:
        mesh=trimesh.load_mesh(R/(('models/'+p['name']+'.stl') if p['printed'] else p['stl']));mesh.vertices=(mesh.vertices-pivots[p['body']])*.001
        mass=(mesh.volume*DENSITY if p['printed'] else p['mass_g']*.001)
        if not p['printed']:
            lo,hi=mesh.bounds;mesh=trimesh.creation.box(hi-lo);mesh.apply_translation((lo+hi)/2)
        per_body[p['body']].append((mass,mesh));extents.setdefault(p['body'],[]).append(mesh.bounds)
        if p['name'].endswith('_foot'):
            # Sole footprint measured from the printed foot, not declared. A hardcoded box
            # here means a change to the foot never reaches the physics model.
            v=mesh.vertices;sole=v[v[:,2]<=v[:,2].min()+.0005]
            soles[p['body']]=(sole.min(axis=0),sole.max(axis=0))
    r=E.Element('mujoco',model='Micro_X_RevC_14');add(r,'compiler',angle='radian',autolimits='true');add(r,'option',timestep='.005',gravity='0 0 -9.81',iterations=80)
    default=add(r,'default');add(default,'joint',damping='.02',armature='.00001',frictionloss='.005');add(default,'geom',friction='1 .005 .0001',condim='3')
    w=add(r,'worldbody');add(w,'geom',name='floor',type='plane',size='3 3 .01',rgba='.85 .85 .8 1')
    xml={};qpos_order=[]
    def body_xml(b):
        parent=L.PARENT[b]
        if parent is None:
            el=add(w,'body',name='trunk_base',pos=vector(L.TRUNK_ORIGIN*.001));add(el,'freejoint',name='trunk_base_freejoint');add(el,'site',name='imu',size='.003',pos='-0.01 0 0.135')
        else:
            j=L.JOINT_OF_BODY[b];el=add(xml[parent],'body',name='x_'+b,pos=vector((pivots[b]-pivots[parent])*.001))
            lo,hi=TRAVEL[j['name']]['min_rad'],TRAVEL[j['name']]['max_rad']
            extra={'stiffness':'.05'} if j['name']=='jaw' else {}
            add(el,'joint',name=j['name'],axis=vector(j['axis']),range=f'{lo} {hi}',**extra);qpos_order.append(j['name'])
        mass,com,I=inertia_of(per_body[b])
        add(el,'inertial',pos=vector(com),mass=f'{mass:.6g}',fullinertia=vector([I[0,0],I[1,1],I[2,2],I[0,1],I[0,2],I[1,2]]))
        xml[b]=el
        for c in [c for c in L.BODIES if L.PARENT[c]==b]:body_xml(c)
    body_xml('trunk')
    def box_geom(b,name,lo,hi,**kw):
        lo=np.asarray(lo);hi=np.asarray(hi);add(xml[b],'geom',name=name,type='box',pos=vector((lo+hi)/2),size=vector((hi-lo)/2),mass='0',rgba='.8 .3 .1 .25',group='3',**kw)
    for side in ['left','right']:
        g=1 if side=='left' else -1;p=pivots[f'{side}_foot']
        lo,hi=soles[f'{side}_foot'];box_geom(f'{side}_foot',f'{side}_foot_collision',lo,[hi[0],hi[1],lo[2]+.0105])
        add(xml[f'{side}_foot'],'site',name=f'{side}_foot',pos=vector((np.array([-25,g*50,13.5])-p)*.001),size='.003')
        for b in [f'{side}_upper_leg',f'{side}_lower_leg']:
            lo=np.min([e[0] for e in extents[b]],axis=0);hi=np.max([e[1] for e in extents[b]],axis=0);box_geom(b,b+'_collision',lo,hi,contype='2',conaffinity='2')
    add(xml['trunk'],'geom',name='trunk_shell_collision',type='ellipsoid',pos=vector((np.array([-6,0,142])-L.TRUNK_ORIGIN)*.001),size='.044 .0376 .024',mass='0',rgba='.8 .3 .1 .25',group='3',contype='1',conaffinity='1')
    add(xml['head'],'geom',name='head_shell_collision',type='ellipsoid',pos=vector((np.array([10,0,247])-pivots['head'])*.001),size='.062 .055 .033',mass='0',rgba='.8 .3 .1 .25',group='3',contype='1',conaffinity='1')
    contacts=add(r,'contact')
    for a,b in [('trunk_base','x_head'),('x_left_upper_leg','x_right_upper_leg'),('x_left_lower_leg','x_right_lower_leg')]:add(contacts,'exclude',body1=a,body2=b)
    act=add(r,'actuator')
    for name in L.ORDER:add(act,'position',name=name,joint=name,kp='5',ctrlrange='-2.4 2.4',forcerange='-.5 .5')
    sensors=add(r,'sensor');add(sensors,'gyro',name='imu_ang_vel',site='imu');add(sensors,'accelerometer',name='imu_accel',site='imu');add(sensors,'subtreeangmom',name='root_angmom',body='trunk_base')
    E.indent(r);E.ElementTree(r).write(R/'models/micro_x_14.xml',encoding='unicode')
    # Standing height at HOME: the absolute trunk height that puts the lowest foot corner on the floor.
    m=mujoco.MjModel.from_xml_path(str(R/'models/micro_x_14.xml'));d=mujoco.MjData(m)
    for i,name in enumerate(qpos_order):
        d.qpos[7+i]=L.HOME[name]
    mujoco.mj_forward(m,d)
    low=min(d.geom_xpos[mujoco.mj_name2id(m,mujoco.mjtObj.mjOBJ_GEOM,f'{s}_foot_collision')][2]-m.geom_size[mujoco.mj_name2id(m,mujoco.mjtObj.mjOBJ_GEOM,f'{s}_foot_collision')][2] for s in ['left','right'])
    # A free joint's qpos[:3] is the absolute body position, so this is a height, not an offset.
    home_z=round(float(L.TRUNK_ORIGIN[2]*.001-low+.001),5)
    total=sum(inertia_of(per_body[b])[0] for b in L.BODIES)
    (R/'engineering/control_interface.json').write_text(json.dumps(dict(joint_names=L.ORDER,home_rad=[L.HOME[n] for n in L.ORDER],observation_size=61,action_size=14,command_size=13,control_hz=50,physics_hz=200,action_scale=1,
        actuator_target='XL330 / BAM M6; assumed kp 200, 7.4 V',geometry='Rev B CAD-derived bodies in the design pose: printed-part meshes at PLA solid density plus purchased envelopes with catalogue masses',
        functional_dimensions='engineering/functional_layout.json',joint_ranges_rad={n:[TRAVEL[n]['min_rad'],TRAVEL[n]['max_rad']] for n in L.ORDER},joint_ranges_source='engineering/joint_travel.json (measured)',
        model_mass_kg=round(total,4),home_trunk_z_m=home_z,physical_verified=False),indent=2)+'\n')
    rig=dict(units='m',root='trunk',root_position_m=list(np.round(L.TRUNK_ORIGIN*.001+np.array([0,0,home_z]),6)),qpos_layout=dict(free=7,joints=qpos_order),
        bodies=[dict(name=b,parent=L.PARENT[b],pivot_m=np.round(pivots[b]*.001,6).tolist(),joint=(L.JOINT_OF_BODY[b]['name'] if b in L.JOINT_OF_BODY else None),
                     axis=(np.round(np.asarray(L.JOINT_OF_BODY[b]['axis'],float)/np.linalg.norm(L.JOINT_OF_BODY[b]['axis']),6).tolist() if b in L.JOINT_OF_BODY else None),
                     home_rad=(L.HOME[L.JOINT_OF_BODY[b]['name']] if b in L.JOINT_OF_BODY else None),mass_kg=round(inertia_of(per_body[b])[0],5)) for b in L.BODIES],
        policy_joints=L.ORDER,mass_kg=round(total,4))
    (R/'models/rig.json').write_text(json.dumps(rig,indent=1)+'\n')
    print(f'Built Rev C 14-axis model, mass {total*1000:.0f} g, HOME trunk height {home_z*1000:.1f} mm')
if __name__=='__main__':build()

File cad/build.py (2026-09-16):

"""Micro X Rev B: actuated chibi T-rex, built in the straight-leg design pose.

World frame: X forward, Y left, Z up, mm. Joint pivots, axes and servo placements come
from engineering/functional_layout.json (measured functional dimensions); every part
around them is original. Each servo is held by a U-channel in one link and drives a
single horn plate on the next, the way the reference robot does it - no clevis
sandwiches - so every part is a thin prismatic shell that prints flat without support.
NOT a physically validated or production-released robot.
"""
from pathlib import Path
import json, math, sys
import cadquery as cq
import numpy as np
import trimesh
sys.path.insert(0,str(Path(__file__).resolve().parent))
import layout as L
import servo as S
from appearance import paint
R=Path(__file__).resolve().parents[1]
for folder in ['models/step','models/print','artifacts','models/purchased']:(R/folder).mkdir(parents=True,exist_ok=True)
MINT=[.97,.95,.88,1];CREAM=[.95,.62,.22,1];GRAPHITE=[.22,.25,.26,1];DARK=[.12,.14,.15,1] # MINT now = warm cream shells, CREAM = amber bill and feet
DENSITY=0.00124 # g/mm3 PLA solid-equivalent; slicer mass with infill is lower
WALL=3.0 # shell wall; Rev C raised from 2.4 for drop strength
ROLL_SWEEP=0.35 # rad of hip-roll clearance carved into the hip bracket
parts=[];purchased=[]

def box(x0,x1,y0,y1,z0,z1):return cq.Workplane('XY').box(x1-x0,y1-y0,z1-z0).translate(((x0+x1)/2,(y0+y1)/2,(z0+z1)/2))
def rbox(x0,x1,y0,y1,z0,z1,r):return box(x0,x1,y0,y1,z0,z1).edges().fillet(min(r,(x1-x0)/2-.01,(y1-y0)/2-.01,(z1-z0)/2-.01))
def vbox(x0,x1,y0,y1,z0,z1,r):return box(x0,x1,y0,y1,z0,z1).edges('|Z').fillet(min(r,(x1-x0)/2-.01,(y1-y0)/2-.01)) # flat top and bottom: prints on its face
def ell(c,h):return cq.Workplane(obj=cq.Workplane('XY').sphere(1).val().transformGeometry(cq.Matrix([[h[0],0,0,c[0]],[0,h[1],0,c[1]],[0,0,h[2],c[2]]])))
def cyl(p,axis,r,length):return cq.Workplane({'Z':'XY','Y':'XZ','X':'YZ'}[axis],origin=tuple(p)).circle(r).extrude(length)
def keep_solid(shape,name):
    shape=shape.clean();solids=shape.solids().vals()
    if len(solids)!=1:
        big=max(solids,key=lambda s:s.Volume());small=sum(abs(s.Volume()) for s in solids if s is not big)
        # abs() matters: a failed boolean can leave an inverted solid whose negative volume
        # cancels the sum and lets a broken part through this guard unnoticed.
        if small>200:raise ValueError(f'{name}: {len(solids)} solids, {small:.1f} mm3 loose')
        for sl in solids:
            if sl is not big:bb=sl.BoundingBox();print(f'  WARNING {name}: dropped {sl.Volume():.1f} mm3 sliver at x {bb.xmin:.1f}..{bb.xmax:.1f} y {bb.ymin:.1f}..{bb.ymax:.1f} z {bb.zmin:.1f}..{bb.zmax:.1f}')
        shape=cq.Workplane(obj=big)
    if not shape.val().isValid():raise ValueError(name+' invalid solid')
    return shape
ROT={'Z':None,'-Z':(math.pi,[1,0,0]),'Y':(math.pi/2,[1,0,0]),'-Y':(-math.pi/2,[1,0,0]),'X':(math.pi/2,[0,1,0]),'-X':(-math.pi/2,[0,1,0])}
def add(name,shape,color,body,print_axis='Z',note='',group='frame'):
    # Re-open every horn bolt path this link owns. Ribs and shells unioned on top of a horn
    # plate silently fill its holes, and a plate you cannot bolt is not a plate.
    for s in L.plates_on(body):
        tool=S.horn_holes(s['P'],s['h'],s['d'])
        a=shape.val().BoundingBox();c=tool.val().BoundingBox()
        if any(getattr(a,k+'max')<getattr(c,k+'min')-.5 or getattr(c,k+'max')<getattr(a,k+'min')-.5 for k in 'xyz'):continue
        shape=shape.cut(tool)
    shape=keep_solid(shape,name)
    path=R/'models/step'/f'{name}.step';cq.exporters.export(shape,str(path))
    restored=cq.importers.importStep(str(path))
    if len(restored.solids().vals())!=1 or not restored.val().isValid():raise ValueError(name+' STEP round trip lost valid solid')
    stl=R/'models'/f'{name}.stl';cq.exporters.export(shape,str(stl),tolerance=.05,angularTolerance=.1)
    mesh=trimesh.load_mesh(stl,process=True);mesh.merge_vertices(digits_vertex=6);mesh.update_faces(mesh.nondegenerate_faces());mesh.remove_unreferenced_vertices()
    if not mesh.is_watertight:
        cq.exporters.export(shape,str(stl),tolerance=.1,angularTolerance=.2);mesh=trimesh.load_mesh(stl,process=True);mesh.merge_vertices(digits_vertex=5);print('  retessellated',name)
    mesh.export(stl)
    if not mesh.is_watertight or mesh.volume<=0:raise ValueError(name+' mesh invalid')
    printable=mesh.copy()
    if ROT[print_axis]:printable.apply_transform(trimesh.transformations.rotation_matrix(*ROT[print_axis]))
    printable.vertices-=np.r_[printable.bounds.mean(axis=0)[:2],printable.bounds[0,2]];printable.export(R/'models/print'/f'{name}.stl')
    vol=shape.val().Volume()
    parts.append(dict(name=name,shape=shape,mesh=mesh,color=color,body=body,group=group,note=note,printed=True,print_axis=print_axis,
        dimensions_mm=np.round(mesh.extents,2).tolist(),volume_mm3=round(vol,1),mass_g=round(vol*DENSITY,2),step=f'models/step/{name}.step',stl=f'models/print/{name}.stl'))
    print(f'  {name:22s} {vol*DENSITY:7.1f} g')
    return shape
def buy(name,shape,color,body,mass_g,note,kind):
    shape=keep_solid(shape,name)
    stl=R/'models/purchased'/f'{name}.stl';cq.exporters.export(shape,str(stl),tolerance=.08,angularTolerance=.15)
    mesh=trimesh.load_mesh(stl,process=True);mesh.export(stl)
    purchased.append(dict(name=name,shape=shape,mesh=mesh,color=color,body=body,kind=kind,mass_g=mass_g,note=note,printed=False,
        dimensions_mm=np.round(mesh.extents,2).tolist(),stl=f'models/purchased/{name}.stl'))

for s in L.SERVOS:
    buy('servo_'+s['name'],S.envelope(s['P'],s['h'],s['d']),DARK,s['body'],S.MASS_G,'XL330-class smart servo envelope; confirm the case hole pattern before ordering','actuator')
def horn(name,**kw):s=L.get(name);return S.horn_plate(s['P'],s['h'],s['d'],name=name,**kw)
def chan(name,**kw):s=L.get(name);return S.channel(s['P'],s['h'],s['d'],**kw)
def pock(name,**kw):s=L.get(name);return S.pocket(s['P'],s['h'],s['d'],**kw)
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

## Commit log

2026-09-08 Create independent Micro X P0 CAD and product development site
    [bom.csv, eye_left.step, eye_left.stl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]
2026-09-08 Normalize manufacturing document line endings
    [bom.csv]
2026-09-08 Add Q4 shared-part quadruped packaging and B2 walking requirements
    [bom_q4.csv, eye_left.step, eye_left.stl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]
2026-09-08 Add expressive eye finish, rear screw retention and durability targets
    [bom.csv, bom_q4.csv, eye_left.step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]
2026-09-08 Add shared camera carrier and opt-in camera and audio bring-up service
    [bom.csv, bom_q4.csv, camera_carrier.step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]
2026-09-10 Redesign commercial Micro X and add anatomy, learning and voice lab
    [bom.csv, camera_carrier.step, camera_carrier.stl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]
2026-09-10 Point the current design reference back to original Microduck
2026-09-10 Revert "Point the current design reference back to original Microduck"
    This reverts commit 50327cf606d9f9c012c0954d7a779c40dc8e9aed.
2026-09-11 Define single-camera Micro X base and deferred stereo variant
2026-09-11 Thicken forearms and shorten blunt toes in printable Micro X CAD
    [camera_carrier.step, eye_left.step, eye_right.step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]
2026-09-11 Remove decorative limbs, add live simulation and report full-stack research and training failures
    [bom.csv, camera_carrier.step, eye_left.step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]
2026-09-12 Rev A: actuated chibi T-rex CAD, CAD-derived dynamics model and complete learning Lab
    Replace the fixed-leg P0 shells with an actuated 15-servo design built around the
    measured Microduck functional joint pivots: brackets with horn/idler clevis plates,
    servo pockets, tail battery tray (NP-F550 class), chest board wall, camera wall, egg
    torso, big-eyed skull with muzzle and servo-driven lower beak. 21 printed parts
    (421.6 g solid PLA equivalent) plus 18 purchased envelopes; 825 g model.
    Derive the 14-axis MuJoCo model from the part meshes (per-link mass and inertia),
    export a poseable GLB rig, and re-run the unchanged official weights on it:
    15/15 trials upright, stationary gates pass, forwar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
    [battery_np_f550.stl, bom.csv, camera_carrier.step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]
2026-09-13 Rev A shell pass: Microduck-simple exterior, no eye/claw parts, mint-cream palette
    Drop the two dome eye parts (the nose camera ring is the eye; eye marks are paint
    only), close the torso into a full egg with the hip zone open underneath, add a neck
    sleeve that hides both neck servos, wrap the knee and ankle servos in a rounded shin
    shell, and put a low cuff around the ankle plates. Palette returns to the P0 mint and
    cream. 20 printed parts, 426.6 g solid PLA; model 830 g.
    Static overlaps 0 and per-joint sweep collisions 0 after the changes; official
    weights still 15/15 upright with stationary gates passing; docs, BOM, drawings,
    portraits and all browser suites regenerated.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
    [bom.csv, chassis.step, chassis.stl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]
2026-09-13 Rev B: rebuild on the measured design pose, single-sided servo mounting, measured joint travel
    Re-derive the whole mechanism from the reference robot's joint layout measured at qpos 0
    (straight legs) instead of the HOME pose. Every joint axis is now world-aligned, so each
    bracket is a prismatic shell that prints flat, and the policy HOME angles stay joint
    angles instead of being baked into the geometry.
    Hold each servo the way the reference does: body in a U-channel on one link, a single horn
    plate on the next, no clevis sandwiches. 20 printed parts at 347 g (was 422 g over 19),
    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
    [battery_np_f550.stl, battery_pack.stl, bom.csv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]
2026-09-14 Prioritize compact Radxa board and add portable CPU policy benchmark
2026-09-14 Rev C: drop the dinosaur, round head with a bill and button eyes, thicker walls everywhere
    Per the owner's direction: not necessarily a dinosaur, just cute and sturdier, still an
    independent design on the measured Microduck joint layout.
    Head becomes a round seven-section loft with a short wide bill, a lens-hood nose and
    Ø20 button eyes grown out of the shell (rooted 8 mm, filleted rim, painted face) - a
    sunken dish was tried first and turned into a crescent where the shell curves away, and
    paint alone bled across the coarse mesh. No separate eye, hand or claw parts.
    Sturdiness: shell walls 2.4 -> 3.0 mm, servo channel walls 2.4 -> 3.0 mm, hip roll rib
    4 mm with top and bottom corner guss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
    [bom.csv, camera_module_3.stl, chassis.step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]
2026-09-14 Rev C finish: duck-proportioned head, amber bill and feet, skirt over the hip servos
    Owner's call was that Microduck simply looks better, so the proportions now follow it
    instead of arguing with it. The head is an eight-section loft sized to the reference head
    envelope, with a wide amber lower bill, a lens-hood nose, nostrils on the bill top and
    Ø22 button eyes grown out of the shell. Palette is warm cream shells with amber bill and
    feet and graphite joints. The neck cover now closes except where the two horn plates pass,
    and the torso skirt reaches down to 116 mm so the hip yaw servos are no longer bare.
    Shrinking the head to reference size pushed the jaw servo outside the shell, so its p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
    [bom.csv, camera_module_3.stl, chassis.step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]
2026-09-16 Audit X the way Micro Cat was audited: it had the same assembly defects
    The tools written for micro-cat found the same faults here, because this is where
    that code came from.
    - A horn plate's bolt holes are filled by the ribs unioned on top of it. The head
    roll plate had all four bolt paths blocked, so the yoke could not be fastened to
    its servo at all. add() now re-cuts every horn bolt path after the link is
    assembled, and tools/fasteners.py walks each bolt axis to check the path is open
    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
    [bom.csv, chassis.step, chassis.stl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]
2026-09-16 Measure the reference robot with the same tipping tool, and fix what that exposed
    tools/tip_study.py can now read a model that carries no named foot collision boxes,
    which is what the reference robot is, so all three can be compared with one
    definition instead of three.
    Doing that returned 0.0 degrees of forward tipping for the reference robot, which
    looked like a bug and was not. Its sole is not flat at HOME: it rests on a heel line
    with its centre of mass 21 mm ahead of that line, so a rigid body there is not in
    equilibrium and pitches forward until the toe lands. The tool now reports the tilt
    where a contact first appears ahead of the centre of mass, and the tilt where the
    last one disap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
    [electronics_fit.py, report.py, tip_study_lib.py]
